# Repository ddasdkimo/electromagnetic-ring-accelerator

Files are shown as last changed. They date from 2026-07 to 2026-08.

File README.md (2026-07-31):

# 電磁環形加速器（Electromagnetic Ring Accelerator）

一個開源科學玩具：鋼球在 3D 列印的環形軌道上，經過線圈加速段被電磁脈衝吸力加速，繞一圈回到原點再次加速，循環往復直到飽和速度。原理是「磁阻式線圈砲（reluctance coilgun）」的環形循環版。

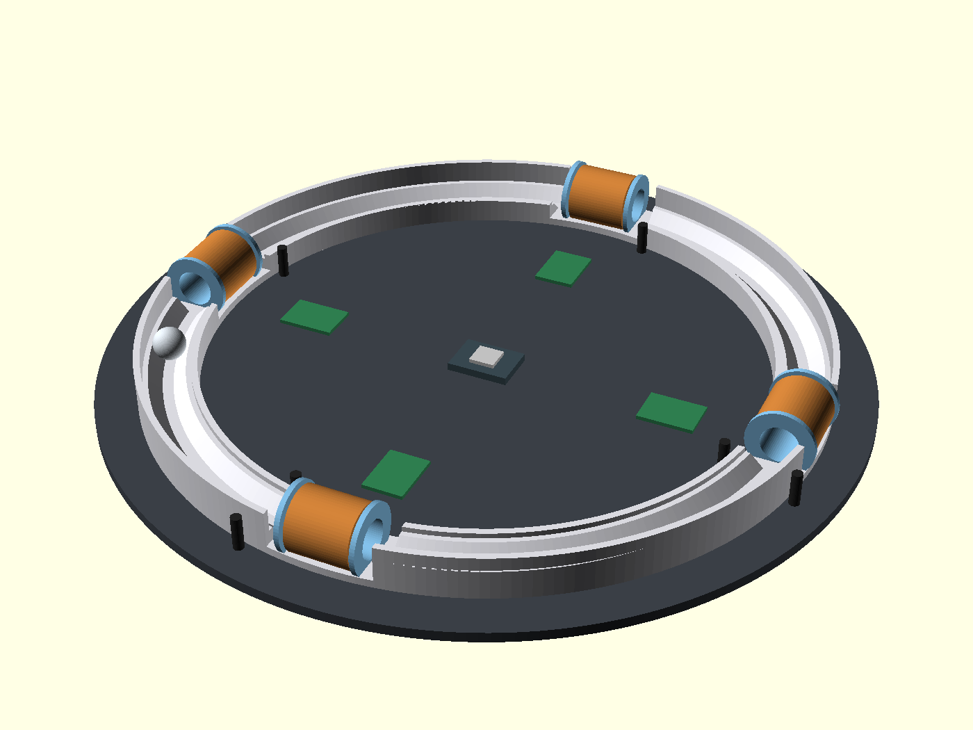
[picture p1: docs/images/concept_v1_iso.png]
概念示意圖

*第一版 3D 概念示意：Ø240 環軌、4 組線圈隧道（銅色）、IR 對射柱（黑）、每級驅動板（綠）與中央 ESP32-S3。模型：[hardware/concept/era_concept_v1.scad](hardware/concept/era_concept_v1.scad)*

> 🚧 專案狀態：**Phase 1 可行性驗證中**——單級直線原型（試配塊已出圖、電路已定稿、韌體已就緒，等待列印與零件到貨實測）。

## 它怎麼運作

1. 線圈通電產生磁場，把鐵磁性鋼球吸向線圈中心，過程中加速。
2. 關鍵在時機：球一過線圈中心，同一個磁場就會反過來拉住它（suck-back）——必須在球到達中心前斷電。
3. 紅外線對射管偵測球接近，ESP32 控制 MOSFET 給線圈一個精準寬度的脈衝。
4. 4 組線圈均布在 Ø240mm 環形軌道上，球每繞一圈被加速 4 次。

有趣的工程發現：在 0.5–3 m/s 的全速域，線圈電流都處於飽和區（τ≈0.65ms 遠短於最短脈寬），所以每級力道都接近上限——調校的重點完全在「關斷時機」，不在電流。

## 規格摘要

| 項目 | 規格 |
|---|---|
| 軌道 | Ø240mm 一體 3D 列印（PETG），45° 雙軌 U 槽 |
| 鋼球 | Ø12.7mm 軸承鋼球（鉻鋼） |
| 線圈 | 0.5mm 漆包線 × 290 匝（8 層），≈1.5Ω / ≈1mH |
| 驅動 | IRLB8721 低邊開關 + SS54 飛輪二極體，12V + 電容組 |
| 感測 | 940nm IR 對射 × 每級 2 道（觸發 + 測速） |
| 控制 | Seeed XIAO ESP32-S3，時序軟體可調 |

## 文件

- [RESEARCH.md](RESEARCH.md) — 原理研究與設計要點
- [PLAN.md](PLAN.md) — 定案方案與階段規劃
- [docs/design-v2-alt.md](docs/design-v2-alt.md) — 方案 B：獨立重新推導的替代設計（傾斜賽道、小球、直線段線圈）與 v1 對照
- [coil-and-driver-spec.md](coil-and-driver-spec.md) — 線圈估算與驅動電路規格（含電路圖）
- [firmware/p1_single_stage/](firmware/p1_single_stage/) — 單級驗證韌體（IR 觸發、脈寬調參、測速、安全保護）
- [docs/log/](docs/log/) — 開發日誌（build log）
- [hardware/preview/](hardware/preview/) — 方案 B 正式件預覽圖（四角件配色、分解圖、隧道剖切）

## 路線圖

- [x] 原理研究、方案定案
- [x] 試配塊 CAD/STL、電路規格、P1 韌體
- [ ] **Phase 1**：單級直線原型實測（驗證可行性）
- [ ] **Phase 2**：環形軌道 + 4 線圈整合
- [ ] **Phase 3**：測速顯示、玩具化收尾
- [ ] 製作影片與心得分享

## 授權

程式碼採 MIT，文件與硬體設計採 CC BY 4.0。歡迎自由複製改作，註明出處即可。

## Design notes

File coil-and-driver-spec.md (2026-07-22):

# 電磁環形加速器 — 單級線圈估算 + 驅動電路規格

> 由 my_car(XIAO ESP32-S3 專案工作區)協力估算。老闆已核可。
> 對應圖文頁:`~/code/2026/my_car/docs/emring-driver.html`(SVG 電路圖 + 表格)

## 前提假設
- 漆包線:0.5mm 裸銅徑(截面 A=π×0.25²=0.196 mm²,銅 ρ=1.72×10⁻⁸ Ω·m,≈0.088 Ω/m)
- 線圈:內徑 15.5mm(隧道外徑)、繞 8 層、約 280–300 匝(取 290 匝 ≈ 36 匝/層)、軸向長 ≈18mm
- 供電:12V;功率級 IRLB8721 + SS54;12V/5A + 5A 保險絲
- 下列為**空管(無鋼球)**估算;鋼球進入孔內時電感顯著上升(可 2–3 倍)

## 1. 線圈電氣參數

| 項目 | 估值 | 公式 / 說明 |
|---|---|---|
| 各層平均半徑 | 8.0 → 11.5 mm(均值 9.5mm) | 首層 15.5/2+0.25;每層 +0.5mm |
| 用線總長 | **≈ 17 m**(280–300 匝:16.7–17.9m) | Σ匝 × 2π·平均半徑 |
| 線圈直流電阻 | **≈ 1.5 Ω**(1.45–1.6) | R = ρL/A ≈ 0.088Ω/m × 17m |
| 迴路總電阻 | ≈ 1.55–1.65 Ω | +IRLB8721 Rds(on)(3.3V 閘極 ~0.016–0.025Ω)+佈線 |
| 電感(空管) | **≈ 0.9–1.1 mH** | Wheeler 多層式 ≈0.92mH;鋼球置中升 2–3× |
| **L/R 時間常數 τ** | **≈ 0.65 ms** | τ = L/R(空管) |
| 穩態電流(理論) | ≈ 7.7 A | 12V / 1.55Ω(需持續導通才達到) |
| **實際脈衝峰值** | **≈ 6–7 A** | 脈寬 1–1.5ms:I=I_max(1−e^(−t/τ)),1ms→6.1A、1.5ms→6.9A |
| 每脈衝磁能 | ½LI² ≈ 0.02 J | — |
| 每脈衝電阻熱 | I²R·t,隨脈寬(低速可達 1–2J) | 低工作週期整體散熱無虞 |

### ⚠️ 關鍵發現:12V/5A 供電偏緊
脈衝峰值 6–7A 超過 5A 額定 → 供電下垂、加速力道打折。
**對策:12V 端並電容組 2200–4700µF(低 ESR),放線圈附近**,由電容供給脈衝峰值、PSU 只補平均值(標準 coilgun 做法)。

### ✅ 元件裕度
- IRLB8721:連續 62A;Vgs(th) 1.35–2.35V,**3.3V 閘極可直驅**(比 IRLZ44N 適合 logic-level,不選 IRLZ44N 正確)。
- SS54(40V/5A 蕭特基):續流 6–7A 短脈衝,平均 5A、突波上百 A,綽綽有餘。

## 2. 建議單級脈衝寬度 vs 球速(0.5–3 m/s)

幾何近似 **w ≈ d_eff / v**,取有效加速段 d_eff ≈ 10mm(進入強力區到線圈中心)。
實務**提早 ~1–1.5ms(≈2τ)關斷**,讓電流尾流在球到中心前衰減、避免 suck-back。

| 球速 v (m/s) | 幾何脈寬 w=d_eff/v | 建議設定(扣 ~1ms 尾流) | 電流狀態 |
|---|---|---|---|
| 0.5 | ≈ 20 ms | ~19 ms | 飽和(~7.7A,注意單發熱) |
| 1.0 | ≈ 10 ms | ~9 ms | 飽和 |
| 1.5 | ≈ 6.7 ms | ~5.7 ms | 飽和 |
| 2.0 | ≈ 5.0 ms | ~4.0 ms | 飽和 |
| 2.5 | ≈ 4.0 ms | ~3.0 ms | 接近飽和 |
| 3.0 | ≈ 3.3 ms | ~2.3 ms | 接近飽和(仍 >電流建立所需) |

**重點結論:** 0.5–3 m/s 全落在「電流飽和區」(τ≈0.65ms,~3ms 就到穩態,而最短脈寬 3.3ms 仍大於電流建立時間)→ 每級電流都能充分建立、力道接近上限;**限制因素是幾何與時序,而非電流上升**。這對 suck-back 調校是好消息:專心調關斷時機即可。

## 3. 單級驅動電路(文字描述)

940nm IR 對射(光電晶體)→ XIAO ESP32-S3 GPIO → IRLB8721(100Ω 串聯 + 10k 下拉)→ 線圈 + SS54 飛輪 → 12V/5A + 5A 保險絲

```
        +12V ────┬──────────────┬───────────── (T5A 慢熔保險絲在此上游)
                 │              │
            [電容組]        線圈上端
          2200–4700µF          │
             (低ESR)         ▓▓▓▓▓  加速線圈 L≈1mH / R≈1.5Ω
                 │           線圈下端 = 節點 D
                 │              ├──────┐
                 │            [SS54]   │        SS54:陰極(帶環端)朝 +12V
                 │          陰極↑陽極↓  │              陽極朝 D。方向接反會短路燒毀。
                 │              │      │
                 │              D──────┘
                 │              │
                 │          [IRLB8721]  低邊開關
                 │           G   D   S
                 │           │       │
   ESP32 GPIO_OUT│──[100Ω]───┤       │
                 │           │       │
                 │         [10k]      │   閘極對地 10k 下拉
                 │           │        │
        GND ─────┴───────────┴────────┴─────────

   IR 發射: 3V3 ─[150–220Ω]─▷│(940nm LED)─ GND      (~15–20mA)
   IR 接收: 940nm 光電晶體, 集極→3V3, 射極→節點→[10k 下拉]→GND, 節點→ESP32 GPIO_IN
            ★ 接收輸出務必落在 0–3.3V,絕不可拉到 12V(會燒 ESP32)
```

### 接法重點
1. **低邊開關**:線圈上端固定 +12V,下端接汲極 D,源極 S 接 GND。
2. **SS54 飛輪**跨接線圈:陰極朝 +12V、陽極朝 D。關斷瞬間吸收線圈反電動勢。**接反=短路燒毀**。
3. **閘極**:GPIO_OUT → 100Ω 串聯 → IRLB8721 閘極;閘極對 GND 加 10k 下拉(開機/浮接確保關斷)。100Ω 開關較慢但振鈴/EMI 小,對單發脈衝夠用。
4. **IR 對射(940nm)**:發射端限流 150–220Ω;接收端輸出加 10k 拉,訊號 0–3.3V,**勿拉 12V**。
5. **保險絲**:12V 端串 **5A 慢熔(T5A)**,**電容組放保險絲之後、線圈之前** → 保險絲只看平均電流(遠小於 5A),脈衝峰值由電容供給,不會誤跳。**用快熔會被 6–7A 脈衝跳掉。**
6. **供電/接地**:ESP32 用自己的 USB 供電,**不要**用 12V 直供;但兩者**必須共地**。12V 大脈衝走粗線、星狀接地,ESP32 訊號地獨立回線,避免地彈跳誤觸發 IR。

## 4. Suck-back 時機 + 測速(ESP32 軟體)
- **Suck-back(吸回)**:鋼球過線圈中心後若還通電,磁力會把球往回拉減速。線圈必須在球**到中心之前**關斷;關斷後電流靠 τ(≈0.65ms)衰減,殘流也會吸,故要**提早關**。
- **時序**:IR 偵測球進入 → 延遲 d → 開 MOSFET 脈寬 w → 關。d、w 依球速逐級微調(這正是用 MCU 的價值)。
- **測速**:同一級用**兩道 940nm IR 對射(已知間距 s)**,量遮斷時間差 Δt → v = s/Δt。ESP32 即時算 v、預測到達中心時間、動態設定下一級 d/w,並記錄各級末速做效率評估。

## 5. 4 級系統延伸(對應你定案:4 路 IR 輸入 + 4 路 MOSFET 輸出)
- 每級一組上述電路;4 顆 MOSFET 閘極接 4 支獨立 GPIO。
- 4 路 IR 輸入建議用**帶硬體比較器/施密特**的模組(或軟體去彈),避免遮斷邊緣抖動誤觸。
- 共用 12V + 電容組;每級 MOSFET 汲極各自的 SS54。
- 一顆球通過:IR1 觸發→算速→開線圈1→...→IR4;逐級末速遞增即驗證加速有效。
```

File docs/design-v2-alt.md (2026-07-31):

# 方案 B：Banked-Square 4（v2 獨立重新設計）

> 這份是**不參考 v1 結論、從物理重新推導**的第二套設計，目的是與 [PLAN.md](../PLAN.md) 的 v1 方案對照。
> 推導過程中發現五個 v1 未涵蓋的量化問題，列在最前面。結尾有「v1 判斷正確、v2 沿用」的誠實清單。

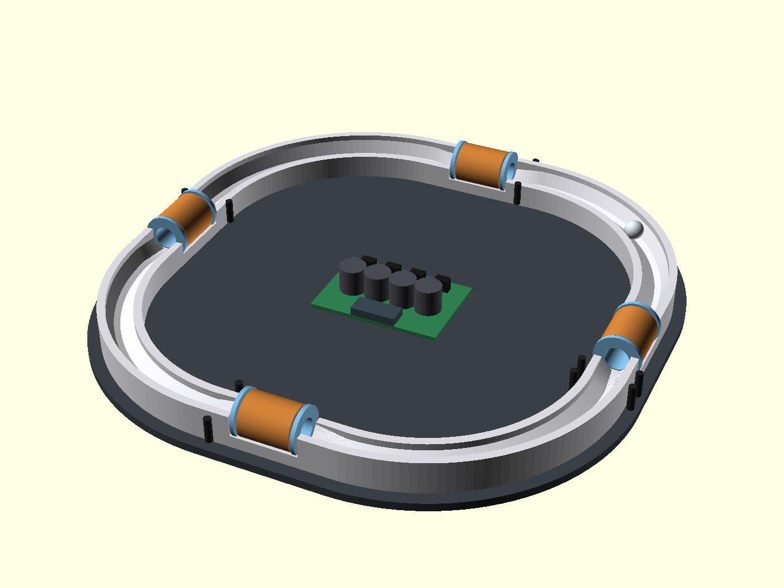
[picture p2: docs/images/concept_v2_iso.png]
v2 概念示意

*方案 B 概念示意：圓角方形軌道（4 直線段 + 4 傾斜彎道）、線圈全在直線段、中央集中驅動板。
模型：[hardware/concept/era_concept_v2.scad](../hardware/concept/era_concept_v2.scad)　俯視圖：[concept_v2_top.png](images/concept_v2_top.png)*

---

## 一、重新推導時發現的三件事

### 發現 1：閉合軌道的側向摩擦損失與軌道形狀完全無關

球轉彎時被外側軌道壁推著轉，側向正壓力 `N = m·v²/r`，沿弧長 `s = r·θ` 積分：

```
W_side = μ·N·s = μ·m·(v²/r)·(r·θ) = μ·m·v²·θ
```

`r` 消掉了。任何閉合迴路 `Σθ = 2π`，所以：

```
W_side = 2π·μ·m·v²   ← 只跟「球重、速度平方、接觸摩擦係數」有關
```

**推論：把軌道做大、做成跑道形、做成圓角方形，一圈的側向摩擦損失一模一樣。**
唯一能真正降低它的手段只有三個：減輕球、降速、**降低 μ**——而降 μ 的正解是**傾斜賽道（banking）**，讓側向力由「滾動的斜面支撐」承擔，而不是「滑動的側牆」。

### 發現 2：v1 的 45° V 槽在 1.08 m/s 就會失效

球騎在 45° 雙斜面上時是滾動接觸（低 μ≈0.02）。但當側向加速度超過斜面能提供的水平分量，球會爬上外壁改成滑動接觸（μ≈0.15，7 倍損失，且噪音與磨耗大增）。

剖面對照

臨界條件：`a_lat = g·tan(θ_外側面)`，`v_max = √(g·tanθ·R)`

| 設計 | 外側支撐角 | 側向承載 | 彎道 R | **乾淨滾動上限速度** |
|---|---|---|---|---|
| v1 | 45° | 1.00 g | 120 mm | **1.08 m/s** |
| v2（banking 20°） | 65° | 2.14 g | 85 mm | **1.34 m/s** |
| v2 極限（banking 25°） | 70° | 2.75 g | 85 mm | 1.52 m/s |

v1 的脈寬對照表涵蓋 0.5–3 m/s，但**物理上球到 1.08 m/s 就會離開 V 槽開始磨外牆**，之後每加速一點都要付 7 倍摩擦。實務巡航速度會卡在 1.1–1.5 m/s 且伴隨明顯磨擦聲。

→ v2 的第一改動：**彎道傾斜賽道（banking）**，成本為零，只是改剖面多邊形的頂點座標。

#### banking 的正確做法：整個 V 槽「繞球心旋轉」

這一步很容易做錯，我第一次也推錯了。兩種做法差很多：

| 做法 | 槽夾角 | 球心高度 | 結果 |
|---|---|---|---|
| ❌ 單獨掰彎兩個面（外 65°／內 35°） | 90°→80° | 比直線段**高 3.34 mm** | 過渡段變成 22% 的陡坡，球會撞上去 |
| ✅ 整個槽繞球心旋轉 20°（外 65°／內 25°） | 維持 90° | **完全不變** | 球心軌跡是水平平面曲線，過渡零高差 |

正解是後者——這正是真實賽車場 banking 的物理意義：**球心的高度與半徑都不動，只有支撐面轉了角度**。
槽的半夾角維持 45°，所以球陷入的深度不變（球心到虛擬頂點恆為 `r√2`）；banking 角 φ 只是把外側面轉成 `45°+φ`、內側面轉成 `45°−φ`。

側向承載只由外側面角度決定，所以承載提升的好處完整保留，而過渡問題自動消失。
φ 上限約 40°（內側面接近水平會失去停放穩定性），實用取 20–25°。

#### 發現 2b：隧道孔心不等於球心（stl 於出圖時抓出，2026-07-28）

我第一版派工單把隧道孔心寫成「= 球心高 8.218」，這是錯的。球在 bobbin 內孔裡是**躺在孔底滾**，不是懸浮在孔軸上：

```
球心 = 孔心 − (孔徑 − 球徑)/2 = 孔心 − (11.2 − 9.5)/2 = 孔心 − 0.85
→ 要讓球心維持 8.218，孔心必須是 9.068
```

若照原派工做，球一進隧道就會**跌落 0.85mm**——正好發生在加速段，是最不該有擾動的地方。

諷刺的是 v1 早就處理對了：`BALL_Z=9.98`、`BORE_Z=10.88`，差 0.90 = (14.5−12.7)/2。
我在 v2 沿用這段幾何時把這個關係弄丟了，寫成了 `BORE_Z = BALL_Z`。**這是 v1 做對、v2 一度做錯的一項。**

連帶修正：法蘭 Ø22 的下緣落在 `9.068 − 11 = −1.93mm`，低於底板基準面，法蘭會穿出底板。

**stl 定案（2026-07-28）：全周底板 3 → 6mm**。

推理過程值得記下來，因為前兩個直覺解都不行：

| 做法 | 為什麼不行 |
|---|---|
| 側面加肉 | 法蘭要的是基準面**下方**的空間，側面加肉在同一 z 範圍，沒用 |
| 只加厚線圈區 | 底面不再是同一平面，253mm 一體大件貼床不均會翹 |
| **全周底板 3→6** ✅ | 底面維持同一平面、貼床面積不減，法蘭槽開在 6mm 厚度裡 |

幾何一律不動，只是底面從 z=0 整體下移到 z=−3。
代價約 +58g（774mm 路徑 × 20 寬 × 3 厚，實心估），換來整圈剛性提升與零翹曲風險。

#### 但加厚還是不夠——最後靠 D 形法蘭釜底抽薪

底板加到 6mm 之後我再算一次膜厚，還是不對：

```
法蘭下緣 −1.932，沉槽挖到 −2.23（含餘裕），底面 −3
→ 剩餘膜厚僅 0.77mm      ← 在磁隙最敏感處，不可接受
```

問題的根源是**法蘭半徑 11 大於孔心到基準面的距離 6.068**，所以圓法蘭必然伸進基準面以下 4.93mm，
底板加多厚都只是把這 4.93mm 往下推，膜厚不會變。

**最終解（stl 定案）：法蘭改 D 形**——下緣截平於基準面下 0.5（z=2.5），沉槽只需挖到基準面下 0.8 的淺槽：

```
截平線距圓心 = 9.068 − 2.5 = 6.568
弦半寬 = √(11² − 6.568²) = 8.82  →  法蘭外形 22 × 17.6
底膜 = 5.20mm（stl CAD 取樣柱量測）
```

從「加厚以容納法蘭」變成「削掉法蘭用不到的部分」，膜厚問題直接消失。
D 形對立印姿態沒有影響。

#### 繞線注意：這副法蘭本來就擋不住線，D 形只是讓它更明顯

D 形的有效擋線角度值得算清楚。線圈外徑 20.8（半徑 10.4），法蘭半徑 11：

```
法蘭邊緣要高過線圈外緣，需距圓心 ≥ 10.4
截平弦上距中點 s 的點，距圓心 = √(6.568² + s²)
  → 需 s ≥ √(10.4² − 6.568²) = 8.06，而弦半長只有 8.82
無擋線角度 = 2·asin(8.06/11) = 94.2°  →  有效擋線 265.8°
```

而且缺口最低點的法蘭半徑 6.568，只比 bobbin 筒身半徑 6.4 高出 **0.168mm**——那一段等於完全沒有側擋。

不過真正的重點是：**即使用完整圓法蘭，裕度也只有 (11 − 10.4) = 0.6mm**，對 0.5mm 漆包線
只夠擋一層多一點。這副 bobbin 從一開始就不是靠法蘭擋線的，是靠繞線張力；D 形只是把這件事挑明。

→ 繞線務必**全程保持張力**，繞完立刻用膠帶／熱縮套／少量瞬間膠固定端頭，不要指望法蘭。
→ 若實測發現線容易鬆脫，截平位置可下修：`z_cut` 越低法蘭越完整，代價是底膜變薄。

| z_cut | 底膜 | 無擋線角度 |
|---|---|---|
| 2.5（現行） | 5.20 mm | 94.2° |
| 1.5 | 4.2 mm | 80.8° |
| ≤ 0.12 | — | 弦半寬會小於筒身半徑，法蘭切進筒身，不可用 |

#### 通則：凡是「圓的東西躺在圓孔裡」，孔心都要抬半個間隙

孔心那個錯不是一次性的失誤——同一個關係在這個專案裡出現了**三次**，其中兩次是 bug：

```
孔心 = 物體軸心 + (孔徑 − 物體徑) / 2
```

| 應用 | 孔徑 / 物體 | 孔心 | 物體軸心 |
|---|---|---|---|
| bobbin 內孔 / 鋼球 | 11.2 / 9.5 | **12.068** | 11.218 |
| IR 夾座槽 / 對射管 | 3.2 / 3.0 | **11.100** | 11.000 |
| ❌ 光路孔誤當定位槽 | 3.5 / 3.0 | 11.000 | **10.750**（偏低 0.25） |

第三列是 stl 在做 IR 夾座時自己踩到並修掉的：光路孔 Ø3.5 一路打穿夾座立柱，
而它比定位槽 Ø3.2 大、孔底（9.25）比槽底（9.5）低，元件會滑進去落到孔底，光軸偏低 0.25mm。
修法是**讓光路孔止於軌道外緣 ±10.5、不進立柱**（實測 STL 頂點確認孔底只到 |x|=10.500 ✓）。

會重複踩到是因為這個關係違反直覺——直覺會說「讓孔心對準物體要走的高度」，
但物體是**躺在孔底**的，不是懸在孔心。定位面是孔的底部，不是孔的軸線。

> 檢查方法：問「這個東西靠什麼面定位？」如果答案是孔的底部，那孔心就不等於物體軸心。

#### 順帶：v1 概念圖的剖面與它自己的球心算式對不上

檢查 `hardware/concept/era_concept_v1.scad` 的 `track_profile()` 多邊形時發現：

```
外側斜面 [20.5,8] → [13.5,3]：Δx=7、Δz=5  →  35.5°   ← 不是 45°
內側斜面 [9.5,3]  → [4.5,8] ：Δx=5、Δz=5  →  45°
```

但同一份檔案的 `BALL_Z = 9.98` 是按**對稱 45°** 算出來的（`r√2 − 平底半寬 + 底板 = 6.35×1.4142 − 2 + 3 = 9.98`）。
兩者不一致，而且錯的方向最不利——**外側比內側還緩**，正好是離心力要壓過去的那一面。

**已向 stl 確認（2026-07-28）：正式件的出圖一直是對稱 45°（Δx=5/Δz=5，與球心 9.98 自洽），
35.5° 只存在於我們的 `era_concept_v1.scad` 示意檔中。**
根因是外側漏了斜面頂點 `[18.5,8]`，多邊形從 `[20.5,8]` 直接連到 `[13.5,3]`。已補上並重新渲染，
v1 的設計本身沒有問題。

### 發現 3：Ø240 圓環上放 30mm 直線圈，球一定會撞隧道壁

直 bobbin 的軸線是圓的**弦**，球從弧形軌道出來時速度沿**切線**，兩者夾角：

```
α = asin(L/2R) = asin(15/120) = 7.18°
30mm 行程的橫向漂移 = 30 × tan(7.18°) = 3.78 mm
隧道總間隙 = 14.5 − 12.7 = 1.8 mm      ← 漂移是間隙的 2.1 倍
```

球會斜著撞進隧道口、沿壁刮擦通過，動能損失與噪音都在最不該發生的地方（加速段）。縮短線圈到 12mm 才勉強達標，但那樣安匝與加速行程都不夠。

→ v2 的第二改動：**軌道改圓角方形，線圈全部放在直線段**，入口角歸零。
（備選：把 bobbin 做成弧形骨架沿 R=120 彎曲，也能解，但手繞弧形筒麻煩。）

---

## 二、第四個發現：恆壓驅動下「安匝與匝數無關」

磁阻力正比於安匝數平方 `(N·I)²`。恆壓驅動時 `I = V/R`，而 `R = ρ·N·l_turn/A`：

```
N·I = N · V·A/(ρ·N·l_turn) = V·A / (ρ·l_turn)
                              ↑ N 消掉了
```

**安匝只由「電壓、線徑截面、平均匝長」決定，繞幾匝完全不影響力道。**
匝數只決定電流大小與電感（響應速度），不決定推力。

這帶來 v2 最大的免費性能槓桿——**把球變小**：

| | v1（Ø12.7 球） | v2（Ø9.5 球） |
|---|---|---|
| 球質量 | 8.38 g | **3.52 g**（0.42×）|
| bobbin 內孔 | 14.5 mm | 11.2 mm |
| 線圈平均匝徑 | 20.0 mm | 15.6 mm |
| 平均匝長 | 62.8 mm | 49.0 mm |
| **安匝（12V、0.5mm 線）** | 2 180 At | **3 200 At**（1.47×）|
| 磁阻力 ∝ (NI)² | 1.00 | **2.15×** |
| **加速度 = 力/質量** | 1.00 | **5.1×** |

球小 → 線圈小 → 匝長短 → 同樣線徑同樣電壓下電阻低、電流大、安匝反而多；同時質量掉一半以上。**加速度提升 5 倍，而且鋼球更便宜、漆包線更省。**

代價：小球對軌道層紋與接縫更敏感（同樣 0.2mm 台階，對 9.5mm 球是相對 2.1% 的障礙，對 12.7mm 球是 1.6%），軌道表面品質要求提高。

---

## 三、第五個發現：v1 的電容組電荷帳沒算過

v1 寫「線圈旁並 2200–4700µF 供脈衝峰值」。實際算一次電荷：

```
單脈衝電荷 Q = I × w = 8A × 10ms = 80 mC
12V/5A 電源在脈衝期間只能供 5A × 10ms = 50 mC
電容必須補 30 mC
```

若只裝 2 顆 2200µF（4400µF），壓降 = 30mC / 4.4mF = **6.8V** → 電壓垮掉一半，力道剩 1/4。

正確做法是把電容組加大並**集中並聯**（4 級不會同時開，分散裝反而各自不夠）：

| 電容組 | v1 @8A/10ms 壓降 | v2 @11A/7ms 壓降 |
|---|---|---|
| 4 400 µF | 6.8 V ❌ | 9.5 V ❌ |
| 9 400 µF | 3.2 V ⚠️ | 4.5 V ⚠️ |
| **18 800 µF（4700×4 並聯）** | **1.6 V ✅** | **2.2 V ✅** |

充電恢復：每級每圈觸發一次（約 0.6s 一次），補 42mC 只需 8.4ms，5A 電源綽綽有餘。

→ v2 明確規定：**4700µF/25V 低 ESR × 4 全部並聯在集中驅動板上**，不分散。
（好消息：v1 採購清單第 5 項本來就寫「2–4 顆」，買到 4 顆就對了，這項不用改單。）

---

## 四、v2 規格表

| 項目 | 規格 | 理由 |
|---|---|---|
| **佈局** | 圓角方形：直線段 60mm ×4 + 彎道 R=85mm ×4（90°），彎心在 (±30, ±30) | 線圈全在直線段，入口角 0° |
| 外廓 / 周長 | 253 × 253 mm / 774 mm | 256 床單件一體印，仍無接縫 |
| **剖面（直線段）** | 對稱 45° V 槽，平底寬 3mm，球心高 5.218mm（相對槽底） | 停放穩定、進出線圈對中 |
| **剖面（彎道）** | 同一個槽繞球心旋轉 20°：外側面 65°、內側面 25°，**球心高度與半徑不變** | 側向承載 2.14g，過渡零高差 |
| **緩和段** | 直線段兩端各 15mm，僅 banking 角 0°→20° 線性漸變（線圈只用中間 30mm） | 球心軌跡全程是水平平面曲線 |
| 鋼球 | **Ø9.5mm（3/8")** 鉻鋼 GCr15，3.52g | 加速度 5.1×、摩擦損失 0.42× |
| bobbin | 內孔 11.2mm、壁 0.8mm、長 30mm、**D 形法蘭 22×17.6**（下緣截平於基準面下 0.5） | 磁隙 0.85mm/邊；截平換來 5.2mm 底膜 |
| **隧道孔心高** | **9.068mm**（= 球心 8.218 + 間隙/2 0.85） | 球躺孔底滾，不是懸在孔心 |
| 底板 | **全周 3 → 6mm**（幾何不動，底面整體下移至 z=−3） | 法蘭需要基準面下方空間；只加厚線圈區會讓底面不平 |
| 線圈 | 0.5mm 漆包線 × 290 匝（8 層），≈1.09Ω / ≈0.6mH，τ≈0.55ms | 安匝 3200 At、峰值 ~10–11A |
| 續流二極體 | **MBR1045 / SB1045（10A/45V）**，或 SS54 ×2 並聯 | 11A 超過 SS54 的 5A 連續額定 |
| 電容組 | 4700µF/25V 低 ESR **×4 並聯，集中** | 見發現 5 |
| 電源 | 12V / 5A（沿用） | 平均功耗僅 ~0.13A，只有瞬時問題，已由電容解決 |
| MOSFET | IRLB8721 ×4（沿用），免散熱片 | 11A×12mΩ×1.2% duty = 0.02W 平均 |
| **感測** | 每級 1 道 IR 觸發（4 對）+ 基準級加 1 道測速（共 **5 對**） | 見下 |
| 控制 | XIAO ESP32-S3（沿用），**非阻塞 esp_timer 時序** | 4 級並行不能用 busy-wait |
| 脈寬起手 | d_eff≈8mm → w ≈ 8/v ms（1.0m/s→8ms、1.34→6ms、0.5→16ms） | |

### 感測方案簡化

v1 每級 2 道 IR = 8 對、16 個對穿孔。v2 改成：

- **每級 1 道觸發 IR**（球到 → 延遲 d → 脈寬 w）
- **速度由級間飛行時間反推**：級距固定 193.5mm，第 N 級與第 N−1 級觸發時戳相減即得平均速度
- **保留 1 級雙 IR** 作為速度標定基準（校正級間法的系統偏差）

省一半接線與孔位，且環形本來就在循環，速度資訊天然存在。
代價：級間法測的是「上一段平均速度」，加速期會略低估 → 脈寬偏長 → 有 suck-back 風險，所以保留基準級做校正。

### 必須新增：軟體限速（巡航控制）

v2 加速度是 v1 的 5 倍，球會一路加速直到撞上 banking 上限 1.34 m/s 然後開始磨外牆。
因此韌體必須做：**測得速度 ≥ 目標速度時跳過該級脈衝**。

這反而是玩具的賣點——可以做「設定巡航速度」、OLED 顯示即時速度、加減速展示。v1 因為推力小可能自然平衡，v2 是主動控制。

---

## 四之二、分件架構選項：「縫藏隧道」

一體印和分件卡榫本來是矛盾的——v2 從一開始就主張一體無縫（鋼球對 0.1mm 台階敏感）。
但 David 提出正式件分件的需求後，stl 找到了調和方案：

**把接縫藏在球摸不到的地方。**

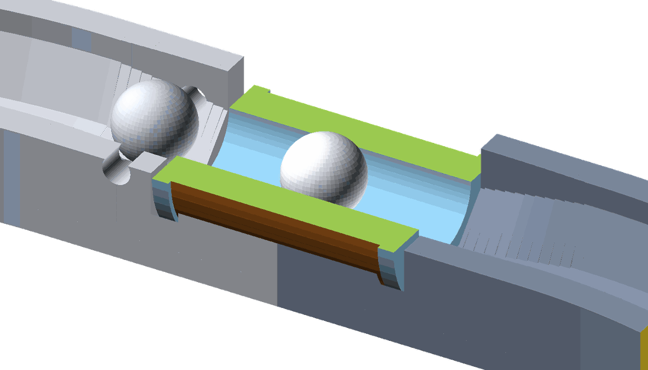
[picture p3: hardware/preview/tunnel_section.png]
隧道剖切

*綠色是 bobbin、藍色是內孔。軌道在線圈段正中斷開，球在隧道內全程騎 bobbin 內孔，摸不到接縫。*

軌道在**線圈段正中**斷開。球通過該處時正在 bobbin 內孔裡（bobbin 長 30，接縫在正中，
球半徑 4.75，兩端各有 15mm 餘裕），接觸的是 bobbin 內孔面而不是軌道——**接縫對球不存在**。

| | 一體印（combo 路線） | 四角件（joint 路線） |
|---|---|---|
| 尺寸 | 253×253 一件 | 4 件各約 145×145 |
| 印壞成本 | 整件報廢 | 重印一角 |
| 翹曲風險 | 大件風險高 | 小件風險低 |
| 接縫 | 無 | 4 個，都藏在隧道內 |
| 對位 | 不需要 | 底部燕尾舌（0.4 間隙）+ bobbin 兼對位銷 |
| 額外需求 | 無 | 需底座提供剛性基準 |

分件版的接合設計（實測 `test_v2_joint_a/b`）：接縫面在 y=30，燕尾搭接 9mm。
**燕尾正上方就是線圈坑**，所以舌中央只有 1.25mm 厚、倒鉤區 2.5–3.0mm，鎖定作用在倒鉤區。
→ stl 建議正式件配底座螺絲，不讓燕尾吃結構力。這個定位是對的：
**燕尾負責對位、螺絲負責承力**，加上 bobbin 本身跨縫兼對位銷，等於三重定位。

### 這裡有一個幾何必然，改不掉

線圈區的底膜只有 **1.268mm**（實測），因為線圈 Ø20.8 的最低點在 z=1.668，
比法蘭 D 面（z=5.5）還低 3.83mm——法蘭區能靠 D 形截平把底膜救回 5.35，
**線圈區沒有這個餘地**。該區剛性要算兩側側牆，不能算底膜。

而分件版的 4 個接縫，正好都落在這個最薄的位置上。這是分件方案要用實測回答的問題。

### 建議的決策方式

不必現在二選一——兩版共用同一個參數化模型，切不切只是一個開關。
合理的做法是 **迭代期用分件**（印壞重印一角，改設計成本低），
**確認幾何全對之後，展示件用一體印**（無縫、最可靠）。
David 的 Bambu H2D（300×320×320）床夠大，一體印始終是可行選項。

## 五、v1 vs v2 對照

| | v1（Ring-4） | v2（Banked-Square 4） | 差異來源 |
|---|---|---|---|
| 軌道形狀 | Ø240 正圓環 | 253mm 圓角方形（直線+彎道） | 發現 3 |
| 線圈入口角 | 7.18°（漂移 3.78mm > 間隙 1.8mm）❌ | 0° ✅ | 發現 3 |
| 剖面 | 全程對稱 45° | 直線 45°／彎道 banking 20°（65°+25°） | 發現 1、2 |
| 乾淨滾動上限 | 1.08 m/s | 1.34 m/s | 發現 2 |
| 鋼球 | Ø12.7 / 8.38g | Ø9.5 / 3.52g | 發現 4 |
| 安匝 | 2 180 At | 3 200 At | 發現 4 |
| 加速度 | 1× | **5.1×** | 發現 4 |
| 每圈摩擦損失 @1.0m/s | ≈2.0 mJ | ≈0.9 mJ | 發現 1、4 |
| IR 對數 | 8 | 5 | 級間測速 |
| 驅動板 | 4 片分散 + 星狀接地 | 1 片集中，單點接地 | 除錯與接地品質 |
| 電容 | 2–4 顆分散 | 4 顆集中並聯（18800µF） | 發現 5 |
| 續流二極體 | SS54（5A） | MBR1045（10A）或 SS54×2 | 峰值 11A |
| 韌體時序 | 阻塞式 busy-wait | 非阻塞 esp_timer × 4 級 | Phase 2 必要 |
| 速度控制 | 無（自然平衡） | 主動限速巡航 | 推力過剩 |
| 周長 | 754 mm | 774 mm | — |

## 六、v1 判斷正確、v2 原封沿用

不為了不同而不同。以下 v1 的決策我重新算過，結論是它對：

- **磁阻式 + IR 觸發 + MOSFET 低邊開關**——這個架構本身沒有更好的替代
- **12V 而非高壓電容放電**——科學玩具的安全性遠比極致速度重要，且循環補能不需要大能量
- **IRLB8721**（3.3V 真 logic-level，TO-220 好焊）
- **一體列印無接縫**（鋼球對 0.1mm 台階極敏感，這個判斷完全正確）
- **PETG 而非 PLA**（線圈發熱，PLA 55°C 會軟）
- **IR 光電晶體集極輸出 + 內部上拉，遮光/斷線皆 HIGH**——fail-safe 極性選得漂亮，這是全案最好的一個決策
- **T5A 慢熔保險絲、電容組接在保險絲之後**
- **12V/5A 電源**（重算平均功耗僅 0.13A，v1 選型沒問題，問題只在電容量）
- **0.5mm 漆包線 8 層**（線徑是安匝的主要槓桿，0.5 是繞線手感與安匝的甜蜜點）

---

## 七、對已完成工作與採購的影響

| 項目 | 影響 | 說明 |
|---|---|---|
| 漆包線 0.5mm ×2 捲 | ✅ 不變 | v2 線更省（匝長短 22%）|
| IRLB8721 ×6 | ✅ 不變 | |
| IR 對射管 ×8 對 | ✅ 不變 | v2 只用 5 對，更寬裕 |
| 電容 2200–4700µF | ⚠️ **改買 4700µF ×4** | 原「2–4 顆」→ 明確 4 顆 4700 |
| 12V/5A 電源、T5A 保險絲 | ✅ 不變 | |
| **鋼球 12.7mm** | ❌ **改 9.5mm（3/8"）** | 尚未下單，現在改零成本 |
| **SS54 ×6** | ⚠️ **加購 MBR1045 ×6** 或 SS54 買 12 顆並聯 | 峰值 11A |
| 電阻包 | ✅ 不變 | 100Ω / 10kΩ 需求相同 |
| 洞洞板 | ⚠️ 改買 1 片大板（7×9cm）取代 4 小片 | 集中驅動板 |
| **試配塊 STL** | ❌ **需重出**：bobbin 內孔 11.2、軌道改 banked 剖面 | 若尚未列印，等新檔 |
| P1 韌體 | ⚠️ 參數改（d_eff 8mm、脈寬表重算），架構不變 | 單級驗證邏輯完全可沿用 |
| coil-and-driver-spec.md | ⚠️ 線圈參數需重算（1.09Ω / 0.6mH / 11A） | |

## 八、v2 未驗證的風險（誠實列出）

1. **9.5mm 小球對列印表面品質更敏感**——若試印後滾動不順，回退 12.7mm 只需放大 bobbin 內孔與槽寬，banking 設計不受影響。
2. **65° 外側面的實際 μ**——理論上仍是滾動接觸，但接觸點靠近球赤道時差速滑移增加，實測可能比 0.02 高。
3. **緩和段仍有「扭轉」**——球心高度不變了，但槽面在 15mm 內轉 20°，球與槽的接觸點會沿球面移動，可能有輕微的滾動軸擾動。做長到 20–25mm 更保險。
4. **圓角方形 + banking 的 SCAD 建模比 rotate_extrude 複雜**——需要直段 linear_extrude + 彎道 rotate_extrude + 漸變段分段內插拼接（概念圖用 15 片近似），正式件應改用連續掃掠，出圖工時較高。
5. **11A 峰值下的線圈溫升**——132W 瞬時、1.2% duty → 平均 1.6W，估計溫升 20–30°C，PETG 安全，但連續高速運轉需實測。
6. **級間飛行時間測速在加速期會低估**——已用基準級校正，但第一圈仍需保守長脈寬冷啟動。

---

*本文件為 v2 獨立設計提案，與 v1 並存供比較，未取代 [PLAN.md](../PLAN.md)。*

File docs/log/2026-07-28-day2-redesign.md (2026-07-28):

# 開發日誌 Day 2（2026-07-28）：重新設計一次，然後在四個來回裡被抓出三個錯

> 部落格素材原稿。這篇的主角不是設計本身，是**兩個 AI 互相審查、一路收斂**的過程。

## 起點：「我換了新模型，重新設計一套讓我比較差異」

Day 1 的方案（v1）已經 ready-to-build，試配塊出圖、電路定稿、韌體就緒。
這時 David 換了模型，要求**不參考 v1 結論、從物理重新推一套**來對照。

這種要求很有意思：如果只是把 v1 微調一下改個名字，那是自欺欺人；
但如果真的從頭推，就必須承擔「推出來的東西可能跟 v1 一樣」的風險——那反而是好消息，代表 v1 是對的。

結果是五個 v1 沒算到的量化結果，其中兩個直接推翻了 v1 的可行速度範圍。

## 重推得到的五件事

### 1. 閉合軌道的側向摩擦與形狀無關

球轉彎被外壁推著走，摩擦功 `W = μ·(mv²/r)·(rθ)` —— **半徑消掉了**。
一圈 `Σθ = 2π`，所以任何閉合迴路都是 `W = 2π·μ·m·v²`。

把軌道做大、做成跑道形、做成圓角方形，一圈的側向摩擦**完全一樣**。
能改的只有 μ 和 m。這一條直接砍掉了「把環做大來減少損失」這個直覺選項。

### 2. v1 的 45° V 槽在 1.08 m/s 就失效

球一旦爬上外側壁，接觸從滾動（μ≈0.02）變成滑動（μ≈0.15），損失跳 7 倍。
臨界條件 `a_lat = g·tan(θ外)`，v1 的 45° 只給 1.0g，`v_max = √(1×9.8×0.12) = 1.08 m/s`。

而 v1 的脈寬對照表涵蓋 0.5–3 m/s——**上面三分之二的速度範圍在物理上是磨著牆跑的**。

解法是傾斜賽道：彎道 banking 20°（外側面 65°），上限拉到 1.34 m/s，**改動成本是零**，
只是移動剖面多邊形的頂點。

### 3. 圓環上放直線圈，球一定刮壁

直 bobbin 的軸線是圓的弦，球出彎時速度沿切線。Ø240 環上 30mm 的線圈：

```
入口角 = asin(15/120) = 7.18°
橫向漂移 = 30 × tan(7.18°) = 3.78mm     隧道間隙只有 1.8mm
```

漂移是間隙的 2.1 倍，球會斜著撞進隧道口刮著過去——而且是在加速段。
解法：軌道改圓角方形，線圈全放直線段，入口角歸零。

### 4. 恆壓驅動下，安匝與匝數無關

這條最反直覺。磁阻力 ∝ `(N·I)²`，而恆壓時 `I = V/R`、`R = ρ·N·l/A`：

```
N·I = N · V·A/(ρ·N·l) = V·A/(ρ·l)      ← N 消掉了
```

**繞幾匝完全不影響力道**，只由電壓、線徑截面、平均匝長決定。
於是「把球變小」成了免費的大槓桿：球小 → 線圈小 → 匝長短 → 安匝反而增加。

Ø12.7 換成 Ø9.5：安匝 +47%、質量降到 0.42×、**加速度 5.1 倍**。

### 5. 電容組的電荷帳從來沒算過

v1 寫「線圈旁並 2200–4700µF 供脈衝峰值」。實際算：

```
單脈衝需要 8A × 10ms = 80mC
12V/5A 電源在脈衝期間只給得起 50mC
→ 電容要補 30mC，4400µF 會垮 6.8V，力道剩 1/4
```

要 4700µF×4 集中並聯（18800µF）壓降才回到 1.6V。
好消息是採購清單本來就寫「2–4 顆」，買滿就對了。

## 然後把它派給 CAD，被打回來

方案寫完、概念圖渲染完、派工單送給負責 CAD 的 `stl` session。
出圖回來附了一句「請核定兩項規格修正」——第一項就打中要害：

### 錯誤 1（我的）：隧道孔心不等於球心

我在派工單寫「隧道孔心 = 球心高 8.218」。錯了。
**球在 bobbin 內孔是躺在孔底滾的，不是懸浮在孔軸上：**

```
球心 = 孔心 − (11.2 − 9.5)/2 = 孔心 − 0.85
→ 孔心必須是 9.068，球心才會維持 8.218
```

照我的派工做，球一進隧道就跌 0.85mm——正好跌在最不該有擾動的加速段。

最諷刺的是 **v1 早就處理對了**（`BALL_Z=9.98`、`BORE_Z=10.88`，差 0.90 = (14.5−12.7)/2）。
我在 v2 沿用這段幾何時，把這個關係寫成了 `BORE_Z = BALL_Z`，把它弄丟了。

> 教訓：重新設計時，最危險的不是你重新推導的部分，是你「照抄」的部分。
> 重推過的地方都被檢查過，抄過來的地方沒有。

### 錯誤 2（我的）：法蘭會穿出底板

連帶問題：法蘭 Ø22 的下緣落在 `9.068 − 11 = −1.93mm`，低於底板基準面。

這裡的來回很有意思，因為**前兩個直覺解都不行**：

| 做法 | 為什麼不行 |
|---|---|
| 側面加肉 | 法蘭要的是基準面**下方**的空間，側面加肉在同一 z 範圍 |
| 只加厚線圈區 | 底面不再同一平面，253mm 一體件貼床不均會翹 |
| 全周底板 3→6 | 底面平了，但膜厚還是只有 0.77mm |

第三個是 stl 提的、我核定的，結果**我們兩個都算錯了膜厚**（它心算成 3.5，我算 0.77）。
它承認算錯之後，順著問題本質找到真正的解：

**根源是法蘭半徑 11 > 孔心到基準面的距離 6.068**，所以圓法蘭必然伸進基準面下 4.93mm，
底板加多厚都只是把這 4.93mm 往下推，膜厚永遠不會變。

**解法：法蘭改 D 形**，下緣截平於基準面下 0.5：

```
截平距圓心 = 9.068 − 2.5 = 6.568
弦半寬 = √(11² − 6.568²) = 8.82   →  外形 22 × 17.6
底膜 = 5.20mm
```

從「加厚以容納法蘭」翻成「削掉法蘭用不到的部分」，膜厚問題直接消失。

### 錯誤 3（它的）：D 形的擋線角度

stl 說「D 形對繞線無影響，法蘭仍有 300°+ 擋線」。這個我算不出來：

```
法蘭邊緣要高過線圈外緣（半徑 10.4），需距圓心 ≥ 10.4
截平弦上距中點 s 的點距圓心 = √(6.568² + s²)
→ 需 s ≥ 8.06，而弦半長只有 8.82
無擋線角 = 2·asin(8.06/11) = 94.2°   →   有效擋線 265.8°
```

而且缺口最低點的法蘭半徑 6.568，只比 bobbin 筒身半徑 6.4 高出 **0.168mm**——那一段等於完全沒側擋。

但追下去發現真正的重點不是 D 形造成的：**即使用完整圓法蘭，裕度也只有 (11−10.4) = 0.6mm**，
對 0.5mm 漆包線只夠擋一層多一點。這副 bobbin 從一開始就不是靠法蘭擋線的，是靠繞線張力。

**D 形沒有製造這個問題，它只是把一個一直存在的問題挑明。**

所以結論是不改設計，改寫文件：繞線全程保持張力、繞完立刻固定端頭。
並把截平高度參數化，留一個備案：`Z_CUT` 從 2.5 下修到 1.5，無擋線角降到 80.8°，底膜 5.2→4.2 仍充裕。

## 另外還翻出一個 v1 的舊帳

重推時順手檢查 v1 的概念圖，發現 `track_profile()` 的外側斜面實際只有 **35.5°**，
但同一份檔案的 `BALL_Z = 9.98` 是按對稱 45° 算的。而且錯的方向最不利——外側比內側還緩，
**正好是離心力要壓過去的那一面**。

問了 stl，答案是：它的正式件出圖一直是對稱 45°，35.5° 只存在於我們的示意檔裡。
追根因是多邊形漏了一個頂點 `[18.5,8]`，從 `[20.5,8]` 直接連到了 `[13.5,3]`。

v1 的設計沒問題，錯的是那張給人看的圖。

## 四個來回之後

| 誰抓到誰 | 內容 |
|---|---|
| stl → 我 | 隧道孔心 8.218 → 9.068（球躺孔底滾） |
| stl → 我 | 法蘭穿出底板，且側面加肉解不了 |
| 我 → stl | 膜厚 3.5 算錯了，實際 0.77（它收回並找到 D 形解） |
| 我 → stl | 擋線 300°+ 算錯了，實際 265.8° |
| 我 → v1 | 概念圖漏頂點導致 35.5°（設計無誤，圖有誤） |

## 三個關於「怎麼做設計」的心得

**1. 獨立重推的價值不在於推出不同答案，在於推出「同樣答案的不同理由」。**
v2 有一長串「v1 判斷正確、原封沿用」的清單——磁阻式架構、12V 而非高壓、一體無接縫、PETG、
IR 集極輸出的 fail-safe 極性。這些在重推後依然成立，反而讓人更敢往下做。

**2. 最危險的不是你算錯的地方，是你沒算的地方。**
隧道孔心那個錯，是因為我「沿用 v1 幾何」而沒重算。重推過的每一處都經得起檢查，
抄過來的那一處出了事。

**3. 「錯的方向」比「錯的數值」更值得注意。**
v1 概念圖的 35.5°、v2 的孔心 −0.85mm，兩個錯都不大，但方向都是**最不利的那一邊**：
一個讓離心力去壓最緩的面，一個讓球在加速段往下跌。數值錯了會被實測抓到，
方向錯了會讓實測結果變得難以解讀。

## 目前狀態

v2 完整設計 + 三件試配塊（含 D 形法蘭新版）已就緒並公開在 repo。
所有幾何經 CAD 驗證：球心 8.218 於直線段／漸變段中點／彎道 22.5° 三處恰相切，干涉 0.000。

接下來卡在實體動作：印試配塊、下單零件。
實測要看四項——滾動順暢度、**banking 過渡有沒有頓一下**（這是 v2 全案的核心假設）、
0.8mm 壁品質、IR 對光。

過了就出正式件。

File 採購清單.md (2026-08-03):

# 採購清單（已核可 2026-07-22，David 執行下單）

依 my_car 單級估算修訂：線圈 ≈1.5Ω/≈1mH、脈衝峰值 6–7A、每脈衝熱 0.08J。
⚠️ 重要新增：**12V 端須並低 ESR 電解電容 2200–4700µF** 放線圈旁供脈衝峰值（12V/5A 電源只補平均，否則峰值時電壓下垂力道打折）。

## 必買（✅ = 2026-08-03 已下單，⬜ = 尚未購）

| # | 狀態 | 品項 | 規格 | 數量 | 建議來源 / 關鍵字 |
|---|---|---|---|---|---|
| 1 | ✅ | 漆包線 | 0.5mm（#25）100g | 2 捲 | ⭐**蝦皮實查**：[漆包線 SWG #14~#47 100g](https://shopee.tw/product/71613488/27211691243) 選 **#25 / 0.5mm**，$165（9折券後約$149），8/5–8/6 到。備選 [今華電子](https://jin-hua.com.tw/webc/html/product/show.aspx?num=533)、[禾樺電子](https://www.ho-hua.com.tw/h/ProductDetail?key=hmqg3&productId=422585)。**注意按長度賣的（如環島科技 0.5mm 只有 10 米）不夠用，單線圈就要 15.3 米** |
| 2 | ⬜ | N-ch MOSFET | **IRLZ44N**（TO-220，55V/47A，**Vgs(th) max 2.0V**，3.3V 可直驅）。原訂 IRLB8721PBF 亦合格，見下方調查節 | 6 | ⭐**蝦皮實查**：[傑森創工](https://shopee.tw/product/20917936/23024196080) $25/顆，9 年店／4.2 萬評價、本品已售 1000+，8/5–8/7 到。<br>⚠️⚠️ **下單前逐字核對料號：勿買 IRFZ44N**（只差一個字母 L）——IRFZ44N 的 Vgs(th) 為 2–4V，**非 logic level，3.3V 驅動會半導通燒毀**。搜尋結果兩者大量混雜。 |
| 3 | ✅ | IR 對射管 | 3mm 940nm IR LED + 光電晶體（成對，單顆裝） | 8 對 | ⭐**蝦皮實查**：[祥昌電子（單顆 $3）](https://shopee.tw/product/27742636/29053212103) 選「**3mm發射器 940nm(透明)**」與「**3mm接收器(黑色)**」各 N 顆，5.0 分/已售 4000+，8/5–8/7 到。⚠️ 收到要確認接收端是**光電晶體**而非 38kHz 解調接收頭——解調型只對調變光反應，連續光遮斷會失效 |
| 4 | ✅ | 蕭特基二極體 | ~~SS54（5A/40V）~~ → **MBRF2045CT（45V/20A，TO-220）**，SS54 撐不住 11A 峰值 | 6 | [buy360-ic](https://shopee.tw/product/26672482/20975998419) $15/顆，內含兩顆共陰極二極體並聯即 20A，TO-220 直插好焊 |
| 5 | ✅ | 電解電容 | 4700µF / 25V（16×27mm）**集中並聯 18800µF**，非分散 | 4 | [祥昌電子](https://shopee.tw/product/27742636/3338460511) $30/顆。非低 ESR 品，但 4 顆並聯等效 ESR 降為 1/4，夠用 |
| 6 | ⬜ | 12V 電源 | 12V 5A DC 變壓器 + DC 母座 5.5×2.1 | 1 | 蝦皮搜「12V 5A 變壓器」 |
| 7 | ⬜ | 保險絲 | **T5A 慢熔**玻璃管 + 保險絲座、船型開關（快熔會被脈衝跳掉；電容組接在保險絲之後） | 各 1 | 同上店家湊單 |
| 8 | ✅ | 軸承鋼球 | **方案 B 改 9.5mm**（市售標準規格是 **9.52mm = 3/8"**，比設計大 0.025mm，對球心高度影響 <0.02mm 可忽略）。鐵磁性，勿買 304 不鏽鋼 | 2 包 | ⭐**蝦皮實查**：[鼎興科技五金 鋼珠全系列](https://shopee.tw/product/6208068/13819042289) 選「**9.52mm(3/8") 50只**」$100，碳鋼、台灣製 ROHS、5.0 分、**8/5–8/6 到**。標題「可被磁鐵吸附本身不附磁性」正合需求（能被吸、不殘磁）。備選 Gcr15 G10 級：[甄甄五金行](https://shopee.tw/product/753006011/29928077211) 9.525mm 100粒 $290，但出貨 2–10 工作日（8/14–8/22）較慢 |
| 9 | ✅ | 電阻 | 100Ω（閘極串聯＋IR LED 限流@3.3V）完整版 12 顆、10kΩ（閘極下拉，必要）4 顆、220Ω–1k（指示 LED，選配）4 顆；光電晶體側免電阻（內部上拉）。IR LED 若改 5V 供電限流換 180–220Ω | 電阻包已有，挑出即可 | my_car 有電阻包 |
| 10 | 🔶 | 萬用板/線材 | v2 改**單片大板**：洞洞板雙面 7×9cm ✅、多芯線 24AWG 紅/黑 ✅（訊號線）／排針 ⬜、矽膠線 18AWG ⬜（線圈走大電流） | 1 批 | 祥昌電子（已購部分）；排針與 18AWG 待補 |

## ✅ 已下單（2026-08-03，4 筆訂單皆「待出貨」，總付款 $953）

| 訂單 / 賣場 | 品項 | 數量 | 訂單金額 | 預計到貨 |
|---|---|---|---|---|
| [鼎興科技五金](https://shopee.tw/product/6208068/13819042289) | 鋼珠 9.52mm(3/8") 50 只／包 | 2 包 | **$200**（免運） | 8/5–8/8 |
| [Mr. ADAPUTA](https://shopee.tw/product/71613488/27211691243) | 漆包線 #25/0.5mm 100g | 2 捲 | **$330**（免運） | 8/5–8/9 |
| [祥昌電子](https://shopee.tw/product/27742636/29053212103) | 3mm 940nm 發射器 ×8、[光敏接收器](https://shopee.tw/product/27742636/29053212103) ×8、[4700µF/25V](https://shopee.tw/product/27742636/3338460511) ×4、[洞洞板雙面 7×9](https://shopee.tw/product/27742636/22434454270) ×1、[多芯線 24AWG 5M](https://shopee.tw/product/27742636/6136173998) 紅／黑各 1 | 6 品項 | **$288**（免運） | 8/6–8/10 |
| [buy360-ic](https://shopee.tw/product/26672482/20975998419) | MBRF2045CT 45V/20A TO-220 | 6 顆 | **$135**（含運 $45） | 8/5–8/8 |

```
商品總金額  $908
運費總金額  $180
運費折抵   -$135   （祥昌／鼎興／ADAPUTA 三家皆達店取 $199 免運）
總付款金額  $953
```

寄送方式：全部蝦皮店到店。付款：貨到付款。

**這批到貨即可完成試配塊的全部 8 項實測。**

### 仍未購（皆非試配階段所需）

| 品項 | 狀況 |
|---|---|
| **MOSFET ×6** | ✅ 已完成候選調查（見下節）。**更正上一輪結論：台灣現在有現貨**，IRLB8721 與 IRLZ44N 皆 8/5–8/7 到。 |
| 12V 5A 電源 + DC 母座 | ✅ 已完成候選調查 |
| T5A 慢熔保險絲 + 座 + 船型開關 | ✅ 已完成候選調查（保險絲有規格陷阱，見下節） |
| 排針、18AWG 矽膠線（線圈大電流） | ✅ 已完成候選調查（矽膠線用量待定） |

**採購時機建議**：以上都屬 Phase 1 電路階段才用得到。
**建議等試配結果出來再下單**——若試配發現機構問題導致設計調整，電路規格可能連帶改變，
提早買反而可能買錯。台灣現貨 2 天到，等試配結果再下單不會拖到進度。

---

## Phase 1 電路料候選調查（2026-08-03，只調查未下單）

### 篩選條件修正紀錄

原訂條件 `Rds(on)@4.5V <15mΩ` **已作廢**。理由：實際佔空比只有 1.03%
（脈寬 6–16ms 隨速度變，但繞行一圈時間同步變化，兩者抵消），
11A、TO-220 無散熱片（Rth_ja≈62°C/W）下：

```
Rds(on) 16mΩ → 溫升 1.2°C
        30mΩ → 溫升 2.3°C
        50mΩ → 溫升 3.9°C
```

**Rds(on) 在本應用不是限制因素**，原門檻是照搬一般功率應用的直覺。
真正該卡的是 **Vgs(th) max** —— Vgs 不足導致半導通時 Rds(on) 會跳到歐姆級，那才是燒毀主因。

**修正後條件**：硬條件 = TO-220 直插 + Vds ≥30V + Id ≥20A + **Vgs(th) max ≤2.5V**；
軟條件 = Rds(on)@4.5V ≤30mΩ；加分 = datasheet 有標 @2.5V／@3.0V 等低壓 Rds(on)
（代表原廠真的驗證過低壓驅動）。

### MOSFET ×6 候選比較

| 料號 | Vgs(th) max | Rds(on)@4.5V | 最低標示 Vgs | Qg | 賣場 | 單價 | ×6 | 交期 | 賣場可信度 | 判定 |
|---|---|---|---|---|---|---|---|---|---|---|
| **IRLZ44N** | **2.0V** | ~30mΩ（@5V 25、@4V 35 內插） | 4.0V→35mΩ | 66nC | [傑森創工](https://shopee.tw/product/20917936/23024196080)（台北中山） | $25 | **$150** | **8/5–8/7** | **9 年店／4.2 萬評價；本品 93 評價、已售 1000+** | ⭐ **綜合首選** |
| IRLB8721PBF | 2.35V | 16mΩ | 4.5V | **7.6nC**（最小） | [久久工坊](https://shopee.tw/product/125966559/52609680201)（新北樹林） | $48（買 4–8 件 **$45**） | $270 | **8/5–8/7** | 7 年店／1084 評價；本品僅 1 評價、已售 22 | 原訂料號，規格最平衡 |
| IRF3708 | **2.0V** | 13.5mΩ | **2.8V→29mΩ**（唯一標低壓） | 24nC | [欣欣科技](https://shopee.tw/product/175283321/55511703605)（桃園蘆竹）／貨種「國產小芯片」 | $39 | $234 | 8/14–8/22 | ⚠️ **0 評價／0 已售** | 規格第一、**貨源最差** |
| IRLB3034PBF | 2.5V（卡上限） | **2.0mΩ**（最低） | 4.5V | **162nC**（最大） | [欣欣科技](https://shopee.tw/product/175283321/57161512578)（桃園蘆竹） | $42 | $252 | >7 天 | 5 評價 | 電氣最強但 Qg 最大 |
| ~~IRL3803~~ | **datasheet 無 max 值** | 9mΩ | 4.5V | 140nC | — | — | — | — | — | ❌ **排除**：Vgs(th) 只標 min 1.0V、Max 欄空白，無法驗證硬條件 |
| ~~AOD4184~~ | — | — | — | — | — | — | — | — | — | ❌ **排除**：AOD 前綴 = TO-252(DPAK) 貼片，無 TO-220 版本（AOT4184 不存在） |

**選型理由**：IRLZ44N 以「規格達標 + 賣場可信度壓倒性 + 最便宜 + 最快到」勝出。
Vgs(th) max 2.0V 比原訂 IRLB8721 的 2.35V 對 3.3V 驅動更安全，Rds(on) ~30mΩ 溫升僅 2.3°C。
IRF3708 規格最優（唯一有 @2.8V 保證）但唯一台灣貨源是 **0 評價的「國產」副廠**——
選它的理由正是原廠 datasheet 的低壓保證，買副廠等於失去該保證，自相矛盾，故不推薦。

⚠️ **選購陷阱**：搜尋 IRLZ44N 會大量混入 **IRFZ44N**（差一個字母 L）。
IRFZ44N 的 Vgs(th) 為 2–4V，**非 logic level，3.3V 驅動會半導通燒毀**。下單前務必逐字核對料號。

### 其他電路料候選

| 品項 | 推薦 | 單價 | 賣場 | 交期 | 淘汰的選項與理由 |
|---|---|---|---|---|---|
| 12V 5A 電源 | [台達電 Delta 原廠](https://shopee.tw/product/313943912/45003887405) 12V 5A（5.5×2.1 通用） | $159 | 台北中山／350 售、4.9 | 8/5 | 祥昌同款 **$329**（選 5A 後才顯示，$89 是 1A 價）貴一倍；虎尾 $297 且接頭 5.5×**2.5** 不合；[板橋 $90](https://shopee.tw/product/18364798/1856376942)（4000+ 售）與 [台中 $70](https://shopee.tw/product/17501736/21494735252) 更便宜但非品牌、需再確認接頭 |
| DC 母座 5.5×2.1 | [祥昌](https://shopee.tw/product/27742636/6448855355) 帶螺紋配螺母 | $8 | 祥昌／1000+ 售 | 8/5–8/7 | 規格直接對上，無需比較 |
| **T5A 慢熔保險絲** | [彰化 Time-Lag 延遲型](https://shopee.tw/product/78246604/22680950485) 選 **20mm_5A** | **$8** | 彰化／5000+ 售、208 評價 | 8/5–8/6 | ⚠️ **祥昌沒有 5A**：其 5×20 慢熔玻璃管只有 30A 單一規格；其 3.6×10 陶瓷絲既非玻璃管、未標慢熔、且**裝不進 20mm 保險絲座** |
| 保險絲座 | [祥昌 20mm 雲母型](https://shopee.tw/product/27742636/7037344005) | $11 | 祥昌／1000+ 售 | 8/5–8/7 | 或 [MT899 20mm 座](https://shopee.tw/product/26028424/10502577494) $16（565 售）。**20mm 座必須配 5×20mm 絲** |
| 船型開關 | [祥昌 2P2S ON/OFF 有段](https://shopee.tw/product/27742636/27607690658) | $22 | 祥昌／1000+ 售 | 8/5 | 開關位於電源入口、承受平均電流（佔空比 1%），一般 6A 規格即足夠 |
| 排針 2.54mm 單排 | [祥昌 台灣製](https://shopee.tw/product/27742636/10813415362) 選 **2.54排針 40PX1 (短)180°** | $20 | 祥昌／4000+ 售 | 8/5–8/7 | 同商品另有 1.27／2.0mm 與雙排，選錯間距無法用 |
| 18AWG 矽膠線 | [祥昌 UL3239](https://shopee.tw/product/27742636/23268803725) 紅／黑分開計價 | **$15／米** | 祥昌／297 評價 | 8/5–8/7 | ⚠️ **按米零剪，用量待定**（見下） |

### 定案

- **MOSFET：IRLZ44N ×6**（傑森創工 $25，$150）。ERA 驗算確認全數達標，
  Qg 66nC 在串 100Ω 時閘極尖峰 33mA（ESP32 安全）、開關 2.0µs 佔 6ms 脈寬 0.033% 可忽略。
  流通量極大的老料號、不易買到假貨，是額外優點。
- **18AWG 矽膠線：紅黑各 2m**。依據：直線段中心線離原點 115mm、驅動板 64×44 置中，
  板邊到線圈直線距離 8.3cm，繞行與彎曲餘裕取 20cm/條 →
  紅（+12V 側 ×4 ＋電源入線）110cm、黑（汲極側 ×4 ＋GND 幹線）120cm，加裁切損耗 → 各 2m。

### 賣場分配：兩案比較

兩家都無法單獨買齊：**MT899 缺矽膠線**（只有一般 PVC 多芯線），**祥昌缺 T5A 保險絲**（只有 30A）。

**方案 A：MT899 一家全包**（18AWG 改用一般多芯線）

| 品項 | 單價 | 數量 | 小計 |
|---|---|---|---|
| [T5A 慢熔保險絲](https://shopee.tw/product/26028424/22020725894) 20mm_5A | $10 | 3（耗材，備用） | $30 |
| [保險絲座 20mm](https://shopee.tw/product/26028424/10502577494) | $16 | 1 | $16 |
| [船型開關 KCD4 20A](https://shopee.tw/product/26028424/18791165438) | $20 | 1 | $20 |
| [排針 2.54 單排](https://shopee.tw/product/26028424/980616905) | $8 | 1 | $8 |
| [DC 電源母座](https://shopee.tw/product/26028424/1120033174) | $10 | 1 | $10 |
| [18AWG **一般多芯線** 3米](https://shopee.tw/product/26028424/907876176) | $45 | 1 | $45 |
| [熱縮套管 φ1~φ20](https://shopee.tw/product/26028424/910728394) /米 | $10 | 2 | $20 |
| [銅柱 M3](https://shopee.tw/product/26028424/903080559) | $3 | 4 | $12 |
| [PVC 絕緣膠帶](https://shopee.tw/product/26028424/657691683) | $20 | 1 | $20 |
| | | **小計** | **$181** |

差 $18 達免運，補 1 米熱縮或數顆銅柱即過。**未找到 M3 螺絲與束線帶，需另尋。**

**方案 B：祥昌湊免運 ＋ MT899 保險絲單**

| 品項 | 單價 | 數量 | 小計 |
|---|---|---|---|
| 排針 2.54排針 40PX1(短)180° | $20 | 1 | $20 |
| 18AWG **矽膠線** UL3239 紅／黑 | $15/米 | 各 2m | $60 |
| DC 母座 5.5×2.1 | $8 | 1 | $8 |
| 保險絲座 20mm 雲母型 | $11 | 1 | $11 |
| 船型開關 2P2S | $22 | 1 | $22 |
| ① [熱縮套管 2mm 黑](https://shopee.tw/product/27742636/5735610649) /米 | $7 | 3m | $21 |
| ② [銅柱 M3 細牙](https://shopee.tw/product/27742636/17791980547) | $2 | 4 | $8 |
| ② [M3 圓頭螺絲 SCR-1](https://shopee.tw/product/27742636/5548757500) 10入 | $15 | 1 | $15 |
| ③ [日洋 PVC 絕緣膠帶](https://shopee.tw/product/27742636/3361362712) | $19 | 1 | $19 |
| ③ [尼龍紮線帶 CU](https://shopee.tw/product/27742636/7436176027) | $20 | 1 | $20 |
| | | **祥昌小計** | **$204**（免運 ✅） |

MT899 另一單：保險絲 $10×3 = $30 ＋ 運費約 $45 = **$75**。**合計 $279。**

> ⚠️ 熱縮取 2m 時祥昌小計為 **$197，差 $2 達免運**——與上一輪祥昌卡在 $198 差 $1 同型。
> 熱縮改 3m（本來就會用到）即過門檻。

**兩案差 $80。唯一的實質規格妥協是線材**：

| | 矽膠線 UL3239 | 一般 PVC 多芯線 | 本應用是否用得到 |
|---|---|---|---|
| 耐溫 | −60~200°C | 80~105°C | 佔空比 1%、每脈衝 0.08J，不接近上限 → **用不到** |
| 18AWG 載流量 | 約 10–16A | 約 10–16A | 兩者皆滿足 11A 峰值 → **平手** |
| 耐反覆彎折 | 極柔軟、可承受數萬次 | 較硬 | **v2 是固定裝置，線接好就不動**，只有組裝／維修拆裝，數十次等級 → **用不到** |
| 剝皮／服貼性 | 較好 | 較差 | 手工焊接舒適度，非可靠度 |

矽膠線的優勢集中在「會動的部位」——機器人關節、移動軸、來回擺動的線束。
v2 沒有這種需求，**一般 PVC 多芯線在本應用沒有實質劣勢**。
此為「可將就」的差異，不同於保險絲慢熔那種「不能將就」的規格。

### 方案排序（ERA 判定）：C > A > B

- **C 最佳**——不妥協線材、省下 MT899 的運費，唯一成本是跑一趟買一個通用耗材。
- **B 最差**——多花 $80 只為換矽膠線，而矽膠線的優勢本應用用不到。
- **M3 螺絲與束線帶不影響方案**：五金行、大創、文具店都有，順手帶即可，
  不值得為它們多開一單。

### ✅ 定案：方案 C（David 2026-08-03 確認）

David 願意就近購買 T5A 慢熔保險絲，因此**全部集中祥昌一單免運**，線材維持原規格的矽膠線。

| 賣場 | 內容 | 商品 | 運費 | 小計 | 到貨 |
|---|---|---|---|---|---|
| 祥昌電子 | 排針、矽膠線紅黑各 2m、DC 母座、保險絲座、船型開關、熱縮套管 3m、銅柱 M3 ×4、M3 螺絲、絕緣膠帶、紮線帶 | $204 | **$0** ✅ | **$204** | 8/5–8/7 |
| 傑森創工 | MOSFET **IRLZ44N ×6** | $150 | $45 | **$195** | 8/5–8/7 |
| 台達電賣場 | 12V 5A 電源（5.5×2.1） | $159 | $45 | **$204** | 8/5 |
| David 自購 | T5A 玻璃管慢熔保險絲（實體電料行）、M3 螺絲與束線帶順手帶 | 約 $10–20 | — | — | — |

**線上實付約 $603**（商品 $513 ＋ 運費 $90）。

**後兩家為何不湊到免運**——兩條路都算過，都不划算：

1. **買湊單品**：傑森創工可湊的是麵包線 $55／麵包板 $25／Micro USB 供電 $15。
   但功率級走 11A，**麵包板接觸電阻大、額定僅 1–2A，線圈電流絕對不能上麵包板**；
   訊號級（4 MOSFET ＋ 4 二極體 ＋ 5 對 IR）又簡單到直接焊洞洞板比搭麵包板還快。
   → 真的用不到，依原則七不硬湊。
2. **換料號併單**：祥昌有含 IRL3705N 的混合型號商品 $35，併進祥昌就免運。
   但 $35×6 = $210 ＞ $25×6 ＋ 運費 $45 = $195，**單價差 $60 吃掉省下的 $45，淨虧 $15**，
   還要承擔規格未驗與選錯規格的風險。→ 維持 IRLZ44N。

> ⚠️ **尚未下單、未加入購物車**——等試配實測綠燈。
> 若試配結果導致機構調整、電路規格連帶改變，本清單需重新檢視。

### 兩項實查得到的技術確認

- **市售標準是 9.52mm（3/8"），不是 9.5mm**。比設計大 0.025mm →
  球心高度差 <0.02mm、孔心差 0.0125mm，皆可忽略，直接用。**不要買 9.0mm**（差 0.5mm 會讓球心低 0.35mm）。
- **祥昌的接收端是「光敏接收器」**（商品圖標示），即光電晶體／光敏二極體，
  不是 38kHz 解調接收頭 ✓ 符合我們「集極輸出＋內部上拉」的設計。
  （解調型只對調變光有反應，用於連續光遮斷偵測會失效——選購時要避開。）

### 二極體選型變更

原訂 SS54（5A/40V）撐不住 11A 峰值。改用 **MBRF2045CT（45V/20A，TO-220）**：
內含兩顆共陰極二極體，兩腳並聯即得 20A，遠超需求；TO-220 直插比 SS54 的 SMD 封裝好焊。

## 既有免購（已確認 2026-07-23）

- 烙鐵、焊錫、三用電表 ✅
- USB-C 線（XIAO ESP32-S3 供電/燒錄）✅
- 電阻包、XIAO ESP32-S3 Sense（my_car）✅

## 電路接法備忘（my_car 定稿，完整版見 `~/code/2026/my_car/docs/emring-driver.html`）

低邊開關：線圈上端 +12V、下端 MOSFET 汲極 D、源極 GND；飛輪二極體跨線圈（**陰極朝 +12V、陽極朝 D，接反直接燒**；
已改用 MBRF2045CT，TO-220 三腳為「陽極1／共陰極(中腳+散熱片)／陽極2」，**中腳接 +12V、兩側陽極併接後接 D** 即為 20A 並聯）；GPIO→22–47Ω→閘極，閘極對地 10k；IR 收端輸出 0–3.3V 勿拉 12V；ESP32 USB 供電、與 12V 共地、星狀接地防地彈跳誤觸發。起手脈寬 w≈1ms，IR 觸發→延遲 d→脈寬 w，由 ESP32 微調；同級兩道 IR 間距 s 測速 v=s/Δt。

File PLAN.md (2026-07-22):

# 電磁環形加速器 — 大致方案（v0.1，2026-07-22）

> **狀態（2026-07-22）**：老闆已核可。stl 已派工出試配塊；my_car 已交付單級估算與電路（`~/code/2026/my_car/docs/emring-driver.html`）：線圈 ≈1.5Ω/≈1mH、τ≈0.65ms、峰值 6–7A、起手脈寬 ≈1ms；**新增需求：12V 端並 2200–4700µF 低 ESR 電容供脈衝峰值**。採購依 [採購清單.md](採購清單.md) 由 David 下單。

原理研究見 [RESEARCH.md](RESEARCH.md)。本檔為整合 `stl`（3D 列印）與 `my_car`（既有硬體）兩個 session 回覆後的定案方向。

## 定案參數

| 項目 | 決定 | 依據 |
|---|---|---|
| 軌道 | 中心圓 Ø24cm、**一體列印**、PETG | H2D 實測可用 300×320；≤24cm 一體印可避免接縫（鋼球高速跑圈對 0.1mm 凸緣敏感）；PLA 55°C 會軟，線圈周邊一律 PETG |
| 線圈段數 | 4 段均布 | 入門夠用，電路複製 4 份 |
| 線圈隧道 | C 形斷面（底部開縫）、壁厚 0.8mm、內徑 14.5mm | stl 建議：球持續滾在軌道面不換面、磁隙最小化；0.4 噴嘴 2 週線立印可行 |
| 鋼球 | 12.7mm（1/2"）軸承鋼球（鉻鋼，鐵磁性） | 需採購 |
| 漆包線 | 0.5mm，繞線層厚 4mm（約 8 層 × ~36 匝 ≈ 280–300 匝） | bobbin 外徑據此定，給 stl 出參數化模型 |
| 感測 | 分立 940nm IR LED + 光電晶體「對射」，裝軌道兩側預留孔（隧道入口前） | ITR9608 槽寬僅 5mm，跨不過 15mm 軌道，不採用 |
| 控制 | XIAO ESP32-S3（my_car 現有）：讀 4 路 IR、出 4 路脈衝，時序軟體可調＋順帶測速 | 比純硬體版好調 suck-back 時機；3.3V logic |
| 功率級 | IRLB8721（3.3V 閘極可驅動）× 4 + SS54 蕭特基飛輪二極體 × 4 | IRLZ44N 在 3.3V 驅動不足，不選 |
| 電源 | 12V 5A DC + 總開關 + 5A 保險絲；ESP32 走 USB 或 buck | 低壓安全；防線圈連續通電過熱 |

## 給 stl 的三個開工數字

- 中心圓直徑：**240mm**
- 線圈段數：**4**
- 線徑/繞線層厚：**0.5mm / 4mm**（bobbin 內徑 14.5、壁 0.8、兩端法蘭、繞線起止孔+出線槽）
- IR 感測孔：**要預留**，隧道入口前軌道兩側 Ø3mm 對射孔，建議沿軌道方向多留 2–3 組孔位供時機微調

## 採購清單（my_car 盤點後的缺件）

- [ ] 漆包線 0.5mm × 100g
- [ ] IRLB8721 × 6（含備品）
- [ ] 940nm IR LED + 光電晶體 × 6 對
- [ ] SS54 蕭特基二極體 × 6
- [ ] 12V 5A 電源 + DC 母座 + 開關 + 保險絲座(5A)
- [ ] 軸承鋼球 12.7mm × 5
- [ ] 萬用板、排針、矽膠線
- [ ] 烙鐵/焊錫/三用電表 — 桌上是否已有待確認

既有可用：電阻包、XIAO ESP32-S3 Sense（my_car）；my_car 並可支援線圈匝數計算與驅動電路圖。

## 階段

1. **Phase 1 — 單級直線驗證**：印短直軌 + 1 個 bobbin（先印 stl 的試配塊），繞一顆線圈、焊一組驅動，用 ESP32 調通「擋光通電→過中心前斷電」時序。
2. **Phase 2 — 環形整合**：Ø24cm 一體軌道 + 4 線圈 + 底座，逐級點亮。
3. **Phase 3 — 玩具化**：測速顯示、外殼修飾、（選配）速度上限保護。

## FDM 配合鐵律（stl 交代）

名義間隙 ≥0.5mm；先印小試配塊再印大件。

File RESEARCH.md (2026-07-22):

# 電磁環形加速器（Electromagnetic Ring Accelerator）研究筆記

科學玩具目標：鋼球在環形軌道上，經過線圈加速段被電磁力加速，繞一圈回到原點再次加速，持續循環直到達到飽和速度。

## 一、基本原理

這類裝置的本質是「磁阻式線圈砲（reluctance coilgun）」的環形循環版：

1. **吸引加速**：線圈通電產生磁場，鐵磁性鋼球被吸向線圈中心（磁阻最小位置），過程中被加速。
2. **關鍵時機（suck-back 問題）**：球一旦越過線圈中心，同一個磁場會反過來把球往回拉、變成減速。所以必須在球到達線圈中心「之前或恰好抵達時」斷電，讓球靠慣性衝出去。
3. **感測觸發**：用紅外線對射管（IR LED + 光電晶體）或霍爾感測器偵測球接近，觸發 MOSFET 讓線圈通電；球離開感測區即斷電。**感測器與線圈中心的相對位置就是時機控制**——調整幾何位置即可調整通電/斷電時機，最簡版本完全不需要微控制器。
4. **循環加速**：球每經過一次線圈就獲得一點動能，繞圈回來再加速。當單圈獲得的能量 = 滾動摩擦 + 空氣阻力 + 渦流/磁滯損耗時，達到飽和速度。

市售同類產品（可當參考範本）：多為 4–6 組線圈均布在直徑 16–25cm 的環形軌道上，12V 低壓供電，每組線圈配獨立的感測+驅動小電路板。

## 二、系統組成

```
[12V 電源] ──> [每線圈一組驅動電路] ──> [線圈] ──> 鋼球
                     ↑
              [IR 對射感測器]（球擋光 → 觸發）
```

### 1. 機構（3D 列印）
- **環形軌道**：U 型或 V 型凹槽，外側要有擋牆（離心力會把球往外推）。建議軌道中心圓直徑 20–30cm，太小則離心力損耗大。
- **線圈加速段**：軌道在此變成一小段「隧道」，外面繞線圈。此段管壁越薄越好（磁隙越小力越大），內徑比球徑大 1–2mm。**線圈附近不可用鐵磁性螺絲或金屬件**。
- **線圈骨架（bobbin）**：可設計成獨立列印件，繞好線再卡進軌道，方便重繞調整。
- **底座**：固定軌道、藏電路板與走線。
- 材料 PLA 或 PETG 皆可（線圈 duty cycle 低、發熱有限）。

### 2. 線圈
- 漆包線 **0.4–0.6mm**（約 AWG 23–26），每個線圈約 **200–400 匝**、繞 3–6 層。
- 線圈軸向長度約等於球直徑（1–1.5 倍），太長會讓斷電時機難抓。
- 12V 下目標電阻約 1–3Ω → 瞬間電流 4–10A（脈衝式，平均功率不高）。
- 匝數多 → 力大但電感大、磁場建立慢，會限制高速時的效果；這是主要需要實驗調整的參數。

### 3. 鋼球
- 直徑 10–15mm 的**軸承鋼球**（chrome steel）最理想。
- ⚠️ 不鏽鋼要挑 420/440 系（鐵磁性）；**304 不鏽鋼不會被磁鐵吸，不能用**。
- 球跑久了會殘磁，可多備幾顆或準備消磁器。

### 4. 感測 + 驅動電路（每線圈一組，免 MCU 版本）
| 元件 | 規格建議 | 作用 |
|---|---|---|
| IR 對射管 | ITR9608 槽型光遮斷器，或分立 940nm IR LED + 光電晶體 | 偵測球進入 |
| N-ch MOSFET | logic-level，如 IRLZ44N、IRLB8721 | 開關線圈大電流 |
| 飛輪二極體 | 1N5408 或 SS54（蕭特基），跨接線圈 | 吸收斷電時的反電動勢突波，保護 MOSFET |
| 前級電晶體/比較器 | 2N2222 或 LM393 | 把感測訊號整形後推動 MOSFET 閘極 |
| 電阻若干 | IR LED 限流、閘極電阻 100Ω、閘極下拉 10kΩ | — |
| 指示 LED（選配） | 每次觸發閃一下 | 除錯直覺 |

- 電源：**12V DC 5A** 變壓器（安全低壓；想更猛可上 24V，但 MOSFET 與線圈要重算）。
- 進階版：改用 Arduino / 555 控制脈衝寬度與延遲，可精細調時序、做速度顯示（再加一組 IR 對管當測速門）。

### 5. 焊接工具
電烙鐵、萬用板（洞洞板）或自製 PCB、杜邦線/矽膠線、三用電表（必備，量線圈電阻與檢查短路）。

## 三、設計要點與陷阱

1. **時機就是一切**：感測器放在線圈入口前方，球「擋光期間通電、離開光路斷電」。斷電點要落在球心到達線圈中心之前。做成可滑動微調的感測器座會省很多事。
2. **先做直線單級原型**：先 3D 列印一段直軌 + 一個線圈 + 一組電路，在桌上驗證能把球打出去、調好感測器位置，再複製成環形多級。這是最重要的開發策略。
3. **高速後時機會漂移**：球越快，磁場建立時間（L/R 時間常數，約幾 ms）相對越吃緊，這決定了飽和速度。線圈不要繞太多匝。
4. **離心力與軌道**：外牆要夠高；U 槽接觸面越光滑摩擦越小（列印後可輕微打磨或選擇讓球走兩條稜線的 V 槽減少接觸面）。
5. **安全**：12V 本身安全，但線圈瞬間電流大——電源要能扛突波、線圈連續通電（球卡住、感測器誤觸發）會發熱，最好在電源端加保險絲（3–5A）與總開關。斷電突波一定要有飛輪二極體。
6. **殘磁與磁化**：線圈斷電後的殘磁與球本身被磁化都會造成拖曳，蕭特基飛輪二極體讓磁場衰減快一點；也有人串小電阻加速放電（代價是突波電壓變高）。

## 四、建議 BOM（4 線圈版粗估）

- 漆包線 0.5mm × 100g 一捲
- 軸承鋼球 12.7mm（1/2"）× 5 顆
- IRLZ44N × 4、ITR9608 × 4（多買備品）
- 1N5408 × 4、2N2222 × 4、電阻包
- 萬用板、排針、線材
- 12V 5A 電源 + DC 母座 + 開關 + 保險絲座
- 3D 列印：軌道分段（拼接）、線圈骨架 × 4、底座

## 五、開發階段規劃

1. **Phase 1 — 單級直線原型**：一個線圈 + 一組電路 + 直軌，驗證加速與時機調整。
2. **Phase 2 — 環形軌道**：設計可拼接的環形軌道與線圈段，先裝 2 個線圈讓球能穩定繞圈。
3. **Phase 3 — 完整版**：4–6 線圈、整合底座與電路、加測速顯示（選配）。

## 參考資料

- 市售 6 線圈環形加速器（規格參考）：https://www.enginediy.com/products/stark-6-coils-ring-accelerator-cyclotron-high-tech-physics-model-1
- Amazon 同類 DIY 套件（原理說明）：https://www.amazon.com/Electromagnetic-Accelerator-Induction-Circular-Experiment/dp/B0F5HBPWDP
- 線圈砲電路教學（thyristor/MOSFET 驅動、IR 觸發）：https://electronoobs.com/eng_circuitos_tut74.php
- GaussGun 工程專案（電路細節）：https://www.instructables.com/GaussGun-Coil-Gun-Electronics-and-Engineering-Proj/
- 彈珠加速器討論串（感測與驅動方案）：https://forum.allaboutcircuits.com/threads/marble-accelerator-for-game-room.209642/

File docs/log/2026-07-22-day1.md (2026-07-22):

# 開發日誌 Day 1（2026-07-22）：從一句構想到「零件到手即可開測」

> 這篇是部落格素材原稿，記錄專案第一天的完整過程。

## 起點

構想只有一句話：「金屬球經過電磁加速裝置往前跑，在環形軌道繞一圈回到原點重新加速」——做成科學玩具，3D 列印外框、自己繞線圈、自己焊電路。

## 原理研究

查了市售同類產品與 coilgun 開源專案後確認核心原理：**磁阻式線圈砲**。線圈把鋼球吸向中心加速，但球一過中心就會被反向拉住（suck-back），所以「在對的時機斷電」是整個專案的靈魂。用 IR 對射管偵測球、MOSFET 開關線圈，感測器與線圈的相對位置＋脈衝寬度就是全部的時機控制。

## 一天內定案的方案

- **機構**：Ø240mm 環軌一體列印（避免接縫，鋼球高速對 0.1mm 凸緣敏感）、PETG、4 線圈段、C 形薄壁隧道 0.8mm（磁隙每省 0.1mm 吸力都有感）、bobbin 一體含法蘭。
- **幾何巧思**：開放段球騎 45° 雙軌（球心高 9.98mm），進隧道改騎 bobbin 內孔底，孔心設 10.88mm 讓球心同高——過渡零落差。
- **電路**：IRLB8721 低邊開關（3.3V 可直驅）+ SS54 飛輪二極體 + XIAO ESP32-S3 時序控制。
- **供電陷阱**：脈衝峰值 6–7A 超過 12V/5A 電源——解法是線圈旁並 2200–4700µF 低 ESR 電容組供峰值、電源只補平均；保險絲要用慢熔 T5A（快熔會被脈衝跳掉）。

## 三個當天學到的工程亮點

1. **全速域電流飽和**：線圈 τ=L/R≈0.65ms，遠短於任何實用脈寬（2.3–19ms）→ 每級推力都接近上限，調校只需專心調關斷時機，完全不用管電流上升。
2. **脈寬對球速表**：w≈d_eff/v。0.5m/s 要 19ms、3m/s 只要 2.3ms——韌體的安全上限一開始設 3ms 差點把慢速段鎖死，靠 review 抓出來。
3. **失效模式是可以「選」的**：IR 光電晶體用集極輸出+內部上拉，遮光=HIGH——於是斷線、發射管失效都會讀 HIGH 而觸發保護停用（fail-safe）；如果選射極隨耦接法，斷線會被誤判成「有光」而漏檢。同一顆零件，接法決定失效時是安全還是危險。

## 目前狀態

試配塊 STL 已出圖（bobbin 薄壁樣 + 軌道弧段樣 + IR 孔樣）、驅動電路含 ASCII 電路圖定稿、P1 單級驗證韌體完成（含脈寬上限、防連發、卡球停用三道保護）。

下一步：列印試配塊 + 零件採購到貨 → Phase 1 單級直線實測。

## 幕後

這個專案由多個 Claude Code session 協作完成：本 session 統籌研究與整合、`stl` session 負責參數化 CAD 出圖、`my_car` session 負責電路估算與韌體 review，跨 session 用 tmux 互傳訊息。一天內從構想跑到 ready-to-build，包含兩輪互相抓錯的 review。

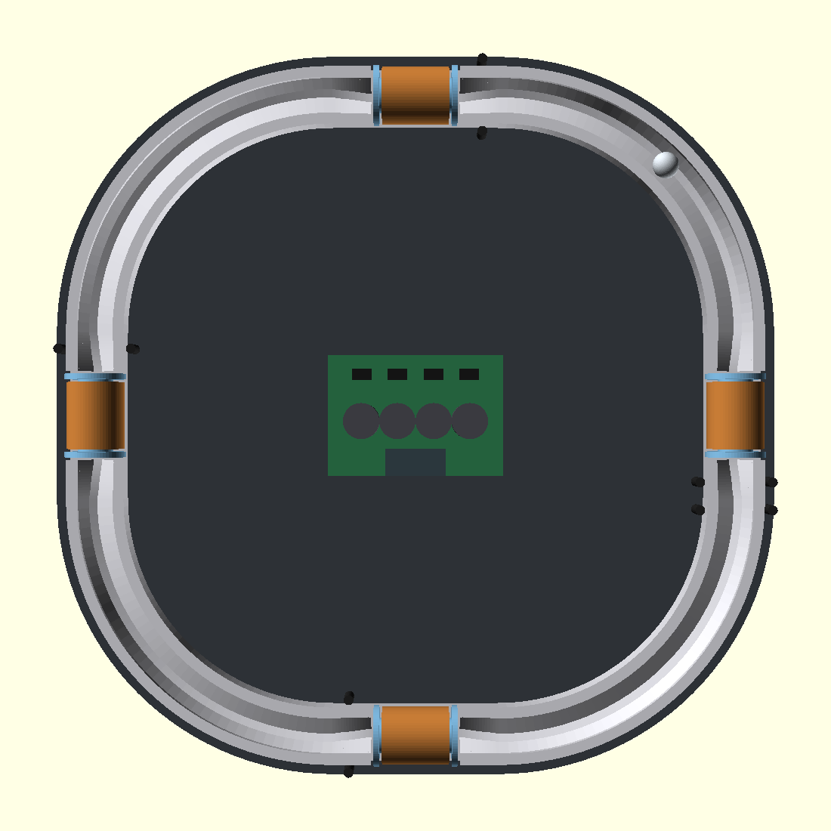
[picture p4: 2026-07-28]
docs/images/concept_v2_top.png

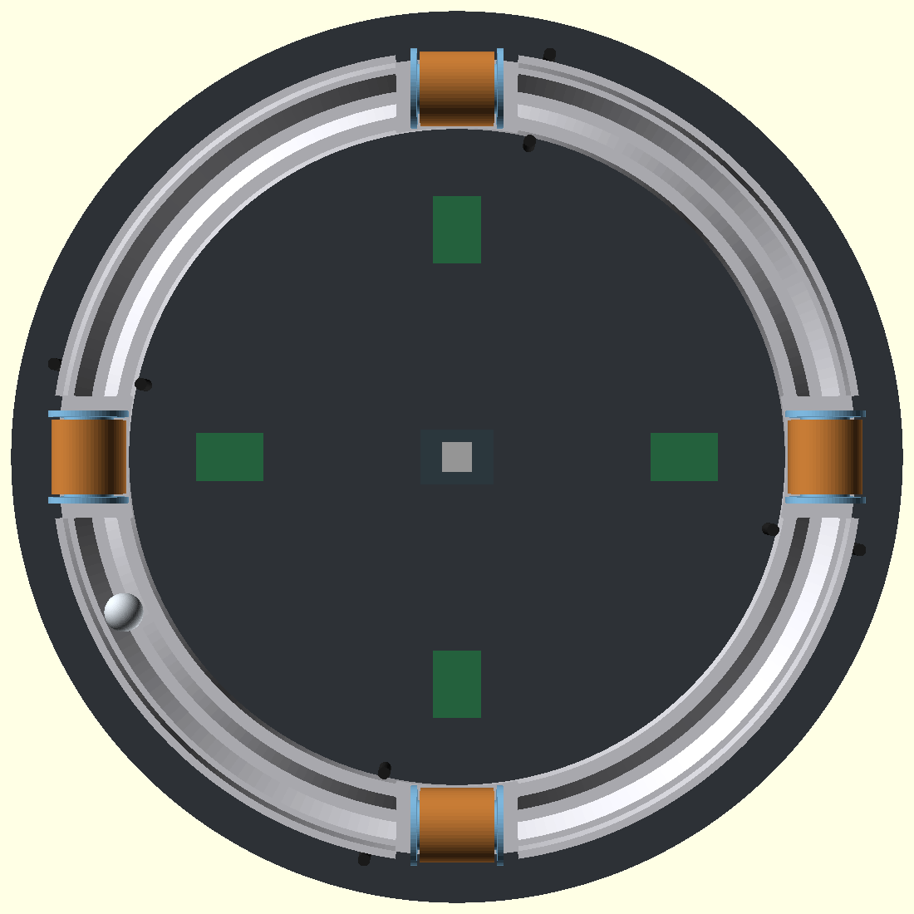
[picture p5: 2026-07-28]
docs/images/concept_v1_top.png

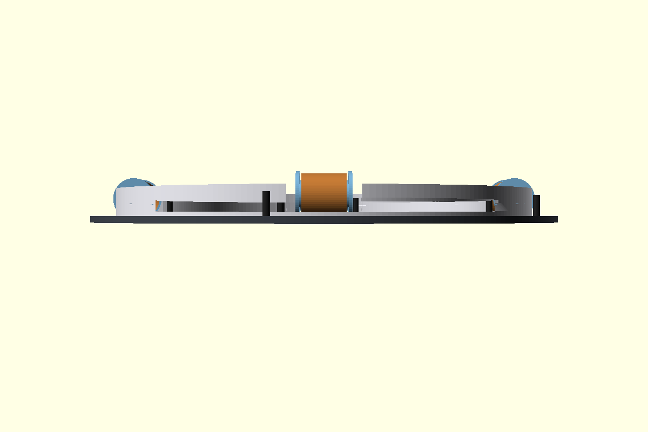
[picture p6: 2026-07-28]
docs/images/concept_v1_side.png

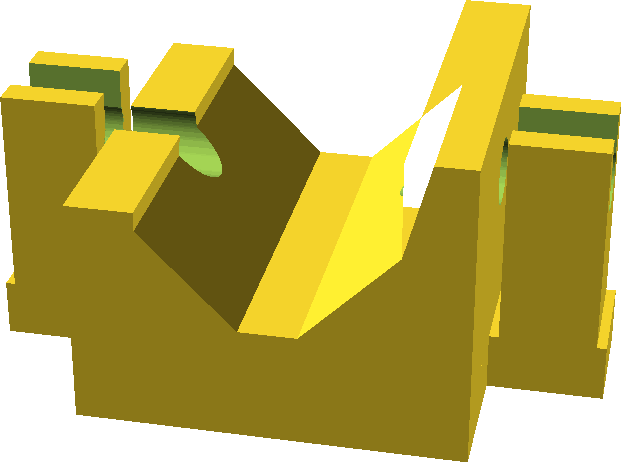
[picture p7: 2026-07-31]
hardware/preview/ir_clip.png

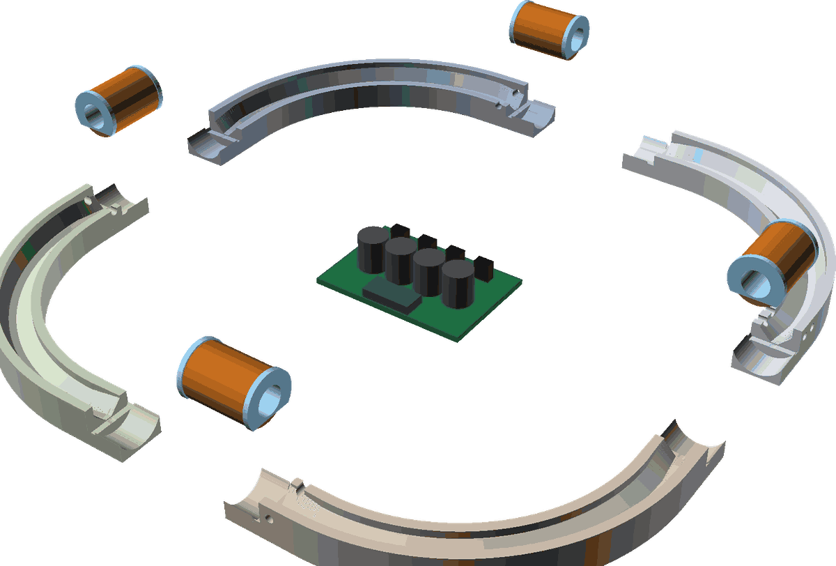
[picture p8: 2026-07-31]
hardware/preview/exploded.png

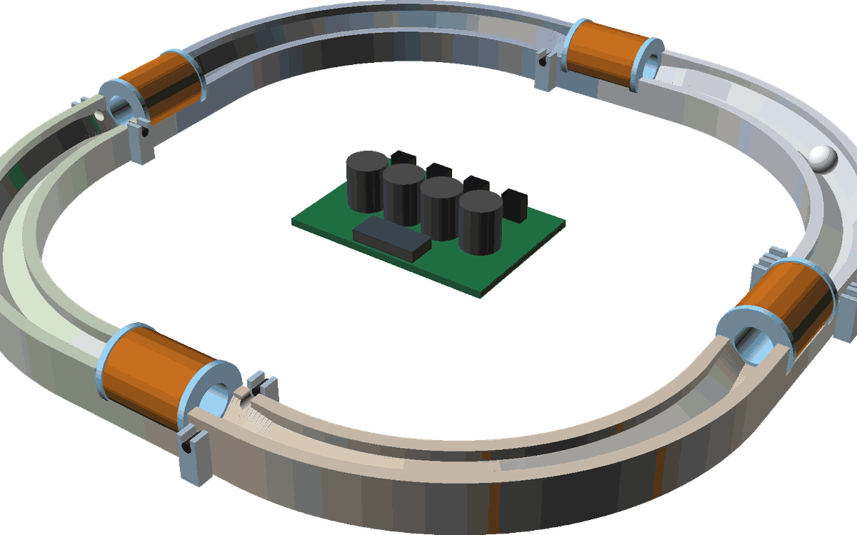
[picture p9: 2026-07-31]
hardware/preview/iso.png

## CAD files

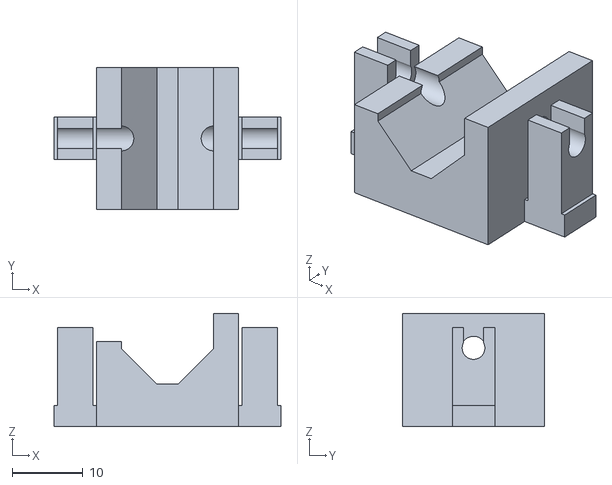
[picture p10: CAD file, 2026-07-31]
hardware/test-fit-v2/test_v2_ir.stl
32.0 x 20.0 x 16.0

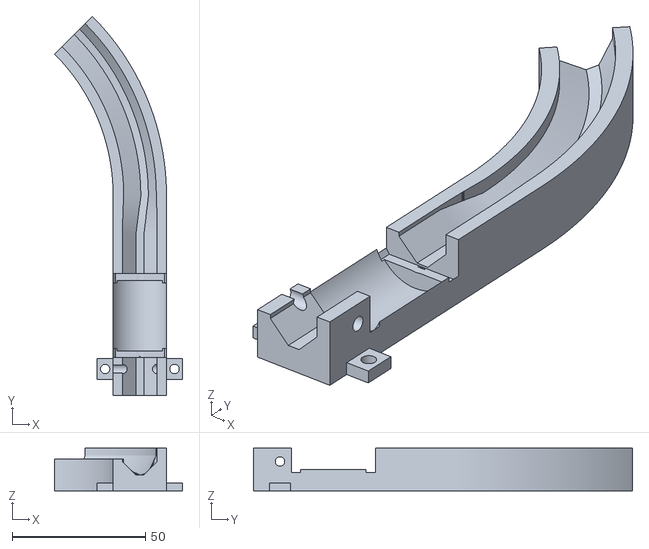
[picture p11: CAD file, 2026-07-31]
hardware/test-fit-v2/test_v2_combo.stl
48.0 x 142.2 x 16.0

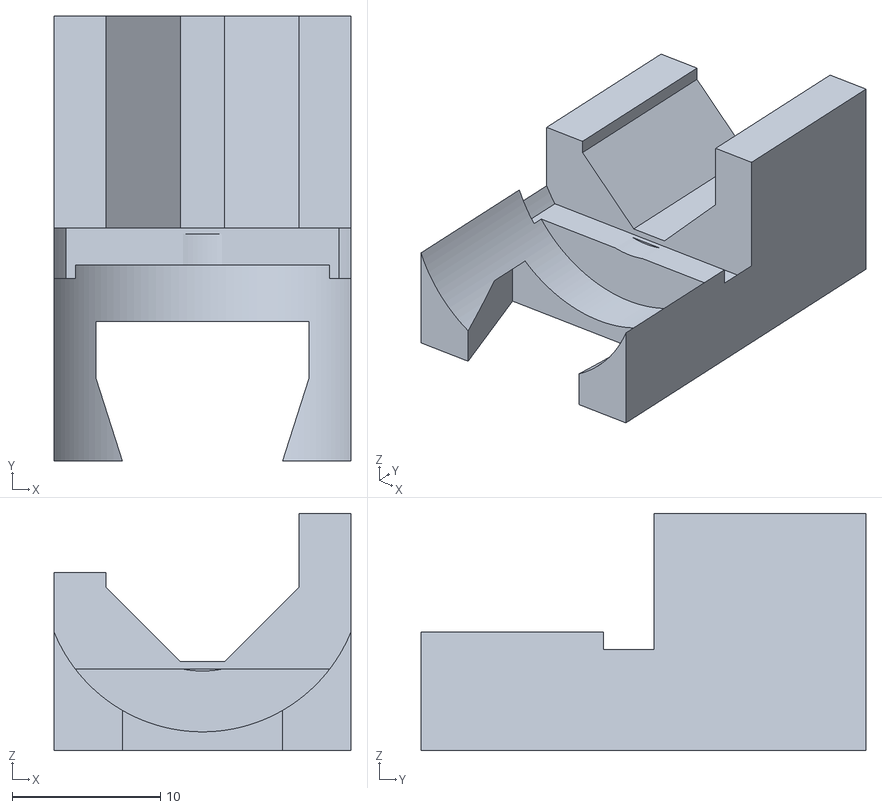
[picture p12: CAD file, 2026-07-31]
hardware/test-fit-v2/test_v2_joint_b.stl
20.0 x 30.0 x 16.0

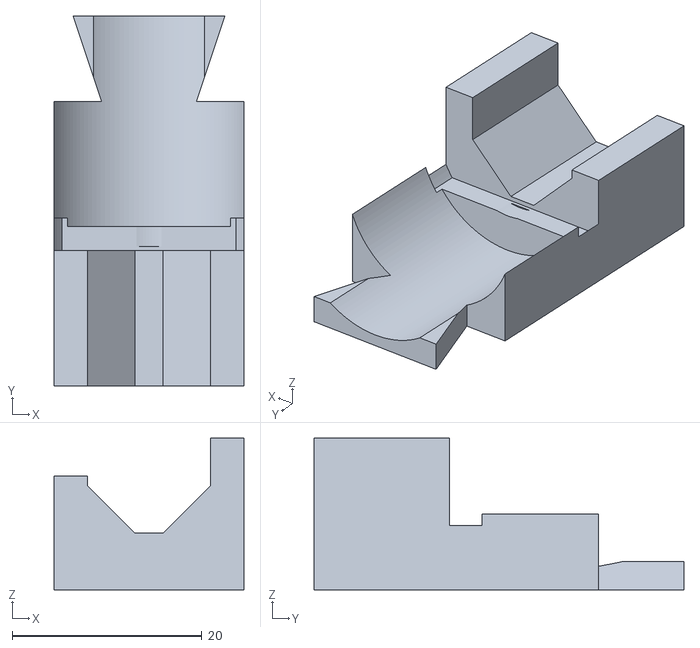
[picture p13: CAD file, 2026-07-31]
hardware/test-fit-v2/test_v2_joint_a.stl
20.0 x 39.0 x 16.0

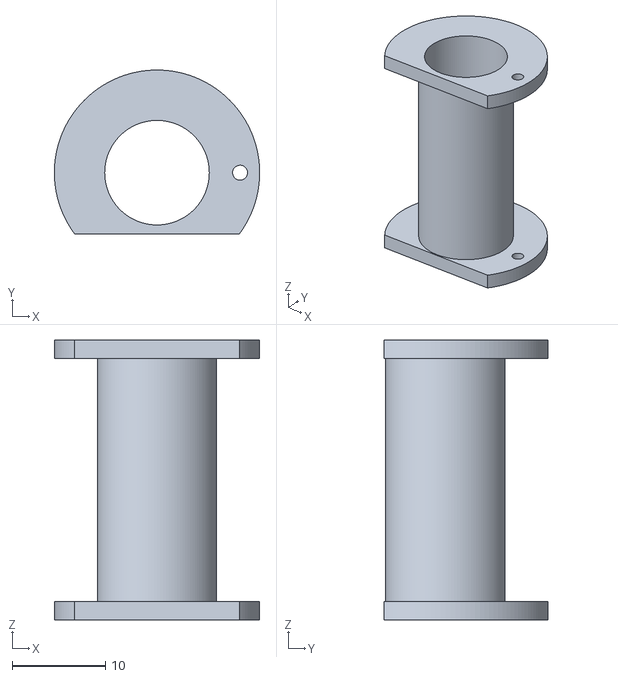
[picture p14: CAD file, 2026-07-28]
hardware/test-fit-v2/test_v2_bobbin.stl
22.0 x 17.6 x 30.0

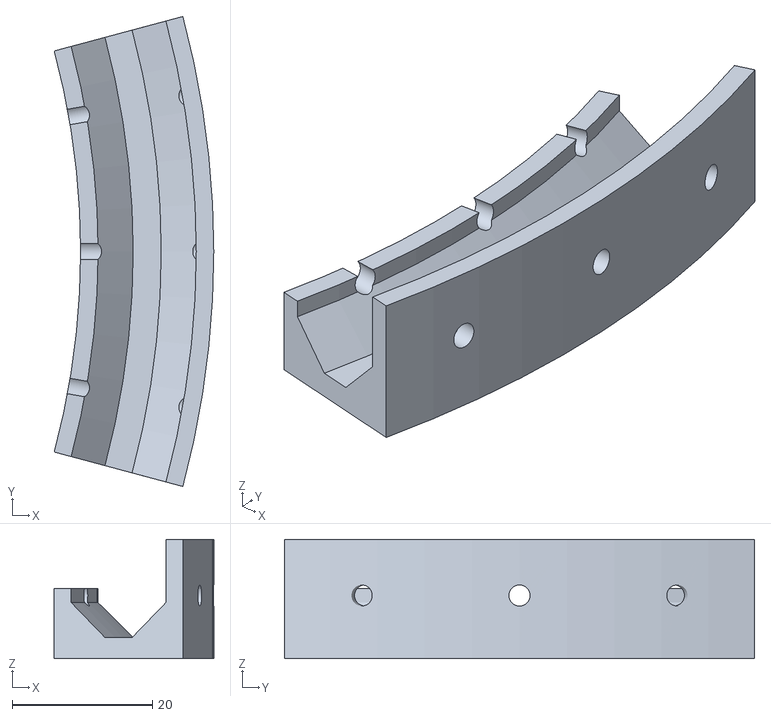
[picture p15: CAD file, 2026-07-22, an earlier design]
hardware/test-fit/test_track.stl
22.8 x 67.0 x 17.0

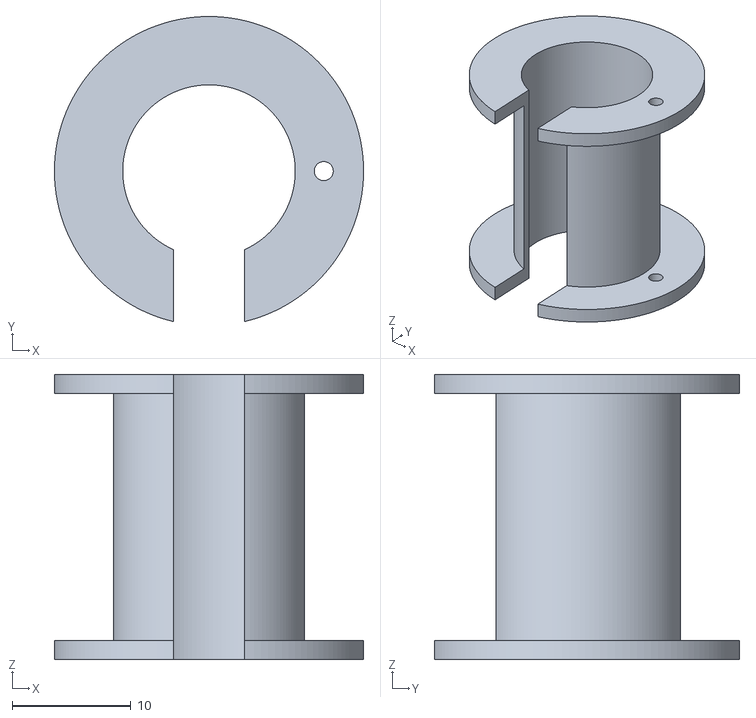
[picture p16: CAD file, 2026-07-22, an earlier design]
hardware/test-fit/test_bobbin.stl
26.0 x 25.6 x 24.0

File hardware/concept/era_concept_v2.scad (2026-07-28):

// 電磁環形加速器 — 方案 B（v2 Banked-Square 4）概念示意圖
// 與 v1 差異：圓角方形（線圈在直線段、入口角 0°）、彎道傾斜賽道 65°/25°、Ø9.5 小球
// 渲染：openscad -o concept_v2.png --preview era_concept_v2.scad

STRAIGHT = 60;      // 直線段長（中間 30 放線圈，兩端各 15 為 banking 漸變段）
R_CORNER = 85;      // 彎道中心線半徑
C = STRAIGHT/2;     // 彎心座標 (±30, ±30)
D = C + R_CORNER;   // 直線段中心線離原點距離 = 115

BALL_D  = 9.5;
BORE_D  = 11.2;     // bobbin 內孔
BASE_Z  = 3;        // 槽底基準面（幾何基準，不隨底板厚度改變）
// 底板全周 3→6：法蘭需要的是基準面「下方」的空間，側面加肉解不了；
// 只加厚線圈區則底面不平、253mm 大件貼床會翹 → 全周下移，底面維持同一平面。
// 幾何一律不動，只是底面從 z=0 下移到 z=−3。代價約 +58g，換整圈剛性。（stl 定案 2026-07-28）
PLATE_BOT = -3;
BALL_Z  = BASE_Z + 5.218;  // 球心高 = r√2 − 平底半寬 = 4.75×1.4142 − 1.5
// 球在隧道內是「躺在孔底」滾，不是懸在孔心 → 孔心必須抬高半個間隙，
// 球心才會與開放段同高。寫成 BORE_Z = BALL_Z 會讓球進隧道時跌 0.85mm。（stl 2026-07-28 抓出）
BORE_Z  = BALL_Z + (BORE_D - BALL_D)/2;   // = 8.218 + 0.85 = 9.068
BANK    = 20;       // 彎道傾斜角（外側面 45+20=65°、內側面 45−20=25°）

NSEG = 15;          // banking 漸變段分片數（示意用；正式件應以連續掃掠生成）

// ---- banking = 整個 V 槽「繞球心旋轉」，槽夾角維持 90° ----
// 關鍵：球心的高度與徑向位置全程不變 → 直線段↔彎道過渡零高差。
// （若改成單獨掰彎兩個面的角度，槽夾角會張開，球陷得較淺、球心抬高 3.3mm，過渡就會有坡。）
function rt(p, phi) = [ p[0]*cos(phi) - (p[1]-BALL_Z)*sin(phi),
                        BALL_Z + p[0]*sin(phi) + (p[1]-BALL_Z)*cos(phi) ];

module profile(t) {
  phi = BANK * t;
  a = rt([ 6.5, BASE_Z+5], phi);   // 外側 45° 斜面頂
  b = rt([ 1.5, BASE_Z  ], phi);   // 平底外緣
  c = rt([-1.5, BASE_Z  ], phi);   // 平底內緣
  d = rt([-6.5, BASE_Z+5], phi);   // 內側 45° 斜面頂
  polygon([[-10,PLATE_BOT], [10,PLATE_BOT], [10,13], [a[0],13], a, b, c, d, [d[0],9], [-10,9]]);
}

// ---- 直線段：中央 t=0，兩端漸變到 t=1 銜接彎道 ----
module straight_side() {
  translate([D,0,0]) rotate([90,0,0]) {
    translate([0,0,-15]) linear_extrude(30) profile(0);   // 中段：線圈區
    for (i = [0:NSEG-1]) {
      t0 = i/NSEG;  seg = 15/NSEG;
      translate([0,0,15 + i*seg])  linear_extrude(seg+0.01) profile(t0);
      translate([0,0,-15 - (i+1)*seg]) linear_extrude(seg+0.01) profile(t0);
    }
  }
}

module corner() {
  translate([C,C,0]) rotate_extrude(angle=90, $fn=160)
    translate([R_CORNER,0]) profile(1);
}

module track() {
  color("#d8d8de") difference() {
    union() {
      for (a=[0,90,180,270]) rotate([0,0,a]) { straight_side(); corner(); }
    }
    // 線圈段清出兩側牆（由 bobbin 隧道取代）
    for (a=[0,90,180,270]) rotate([0,0,a])
      translate([D,0,BASE_Z+10]) cube([26, 32, 20], center=true);
  }
}

// ---- 線圈組（bobbin 內孔 11.2、D 形法蘭 22×17.6、0.5mm×290匝 外徑約 20.8）----
// 圓法蘭 Ø22 的下緣落在 BORE_Z − 11 = −1.93，會伸進底板很深、逼出很薄的底膜。
// 解法（stl 定案）：法蘭下緣截平於基準面下 0.5（z=FLANGE_CUT），沉槽只需淺淺一道，
// 底膜回到 5.2mm。截平弦半寬 = √(11² − (BORE_Z−FLANGE_CUT)²) = 8.82 → 全寬 17.6。
FLANGE_CUT = BASE_Z - 0.5;   // = 2.5

module coil_section() {
  rotate([90,0,0]) {
    color("#7ab3d9") {
      difference() {
        cylinder(d=BORE_D+1.6, h=30, center=true, $fn=64);
        cylinder(d=BORE_D, h=32, center=true, $fn=64);
      }
      for (s=[-1,1]) translate([0,0,s*14]) difference() {
        cylinder(d=22, h=2, center=true, $fn=64);
        cylinder(d=BORE_D, h=4, center=true, $fn=64);
        // D 形截平：局部 −y 對應全域下方（本模組整體 rotate([90,0,0])）
        translate([-15, -(BORE_Z-FLANGE_CUT)-20, -3]) cube([30, 20, 6]);
      }
    }
    color("#c47a35") difference() {
      cylinder(d=20.8, h=24, center=true, $fn=64);
      cylinder(d=12.9, h=26, center=true, $fn=64);
    }
  }
}

// v2 感測：每級 1 道觸發 IR；其中一級（a=0）加第 2 道作測速基準
module ir_gate(a, y) {
  rotate([0,0,a]) for (side=[-1,1])
    translate([D + side*13, y, 0]) color("#222") cylinder(d=3.5, h=12, $fn=24);
}

// ---- 組立 ----
// 底座（圓角方形板，讓在軌道加厚後的底面 z=PLATE_BOT 之下）
color("#3a3f46") translate([0,0,PLATE_BOT-4]) linear_extrude(4)
  hull() for (sx=[-1,1], sy=[-1,1]) translate([sx*C, sy*C]) circle(r=R_CORNER+16, $fn=120);

track();

for (a = [0,90,180,270]) {
  rotate([0,0,a]) translate([D,0,BORE_Z]) coil_section();
  ir_gate(a, -24);                      // 每級觸發道
}
ir_gate(0, -34);                        // 基準級的第 2 道（測速）

// 集中驅動板：4× MOSFET + 4700µF×4 並聯 + XIAO ESP32-S3（坐在底座上）
translate([0,0,PLATE_BOT]) {
  color("#2e7d4f") translate([0,0,1]) cube([64,44,2], center=true);
  for (i=[-1.5:1:1.5]) color("#1a1a1a") translate([i*13, 15, 4]) cube([7,4,9], center=true);
  for (i=[-1.5:1:1.5]) color("#4a4a52") translate([i*13, -2, 8]) cylinder(d=13, h=14, center=true, $fn=32);
  color("#37474f") translate([0,-17,4]) cube([22,10,4], center=true);
}

// 鋼球在彎道上（球心高度與徑向位置和直線段完全相同）
rotate([0,0,45]) translate([C*sqrt(2) + R_CORNER, 0, BALL_Z])
  color("#cfd6dd") sphere(d=BALL_D, $fn=64);

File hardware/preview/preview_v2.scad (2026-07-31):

// ============================================================
// ERA v2 正式件「完成品」預覽（Banked-Square 4）
// 純視覺用途——幾何參數與 test_fit_v2.scad 同源，但不作為出圖檔。
// 用途：讓 David / ERA 在下正式件之前先看整體長相與分件方式。
//
// 渲染：
//   openscad -o preview_iso.png  --preview --autocenter --viewall --imgsize=1600,1200 \
//            -D 'view="iso"' preview_v2.scad
// view = iso | top | corner | section | explode | testfit
// ============================================================
view = "iso";
$fn = 64;

// ---- 幾何（與 test_fit_v2.scad 同源）----
BALL_D  = 9.5;
BASE_Z  = 3;                    // 槽底距「加厚底之上」的高
BALL_Z  = BASE_Z + 5.218;       // 8.218（局部）
BANK    = 20;
STRAIGHT = 60; R_C = 85;
C  = STRAIGHT/2;                // 30
DD = C + R_C;                   // 115：直線段中心線離原點
PLATE = 3;                      // 加厚底（全周，正式件定案）

BOB_ID = 11.2; BOB_WALL = 0.8; BOB_OD = BOB_ID + 2*BOB_WALL;
BOB_LEN = 30; FLANGE_D = 22; FLANGE_T = 2;
BORE_Z = BALL_Z + (BOB_ID-BALL_D)/2;   // 9.068
Z_CUT  = 2.5; FL_FLAT = BORE_Z - Z_CUT;
COIL_OD = 20.8; CRADLE_T = 2.7;
IR_D = 3.5; IR_Z = 8;
NSEG = 12;                      // 預覽用（出圖件是 30）

AXZ = PLATE + BORE_Z;           // 隧道軸心絕對高 12.068
BZ  = PLATE + BALL_Z;           // 球心絕對高 11.218

// ---- 剖面（原式）----
function rt(p, phi) = [ p[0]*cos(phi) - (p[1]-BALL_Z)*sin(phi),
                        BALL_Z + p[0]*sin(phi) + (p[1]-BALL_Z)*cos(phi) ];
module profile(t) {
  phi = BANK * t;
  a = rt([ 6.5, BASE_Z+5], phi);
  b = rt([ 1.5, BASE_Z  ], phi);
  c = rt([-1.5, BASE_Z  ], phi);
  d = rt([-6.5, BASE_Z+5], phi);
  polygon([[-10,0], [10,0], [10,13], [a[0],13], a, b, c, d, [d[0],9], [-10,9]]);
}

// ---- 隧道座（v3：線圈有位、法蘭 D 槽定位）----
// 半座：只長「接縫本側」那一片，另一片由相鄰角件長 → 合起來剛好夾住 bobbin
module tun_add_half() {
  translate([DD-10, 14-CRADLE_T/2, 0]) cube([20, CRADLE_T, PLATE+13]);
}
module tun_cut_at() {
  translate([DD, 0, AXZ]) rotate([90,0,0]) cylinder(d=COIL_OD+0.8, h=26.4, center=true);
  translate([DD, 0, AXZ]) rotate([90,0,0]) cylinder(d=13.4, h=BOB_LEN+0.6, center=true);
  for (sf=[-1,1]) {
    translate([DD-9.12, sf*14-(CRADLE_T+0.7)/2, PLATE+Z_CUT]) cube([18.24, CRADLE_T+0.7, 20]);
    intersection() {
      translate([DD, sf*14, AXZ]) rotate([90,0,0])
        cylinder(d=FLANGE_D+0.6, h=CRADLE_T+0.7, center=true);
      translate([DD-15, sf*14-3, PLATE+Z_CUT]) cube([30, 6, 20]);
    }
  }
  translate([DD-11, -12, PLATE+6]) cube([22, 24, 12]);
}
// IR 光路：止於軌道外緣 ±10.5，不可打進夾座立柱
// （Ø3.5 孔底比 Ø3.2 槽底低 0.25，打穿的話元件落到孔底、光軸就偏了）
module ir_beam_hole(y) {
  translate([DD-10.5, y, PLATE+IR_Z]) rotate([0,90,0]) cylinder(d=IR_D, h=21);
}

// ---- 半段直線：y 0..30（0..15 為 t=0 線圈區，15..30 漸變）----
module half_straight() {
  translate([DD,0,0]) {
    translate([0,0,PLATE]) rotate([90,0,0]) {
      translate([0,0,-15]) linear_extrude(15.01) profile(0);
      for (i=[0:NSEG-1]) {
        t = i/(NSEG-1);
        translate([0,0,-(15+(i+1)*15/NSEG)]) linear_extrude(15/NSEG+0.02) profile(t);
      }
    }
    translate([-10,0,0]) cube([20, 30, PLATE]);           // 加厚底
  }
}
module corner90() {
  translate([C,C,0]) rotate_extrude(angle=90, $fn=240) {
    translate([R_C, PLATE]) profile(1);
    translate([R_C-10, 0]) square([20, PLATE+0.01]);      // 加厚底
  }
}

// ---- L 形角件：半直線 + 彎道 90° + 鏡射半直線 ----
// 接縫落在 (±115, 0) / (0, ±115) —— 也就是每個線圈隧道的正中央
// datum_gate：基準級多開一道測速孔（ERA：每級 1 道 + 基準級加 1 道 = 5 對）
module quarter(datum_gate=false) {
  difference() {
    union() {
      half_straight(); corner90(); mirror([1,-1,0]) half_straight();
      tun_add_half();  mirror([1,-1,0]) tun_add_half();
    }
    tun_cut_at(); mirror([1,-1,0]) tun_cut_at();
    ir_beam_hole(20);
    if (datum_gate) ir_beam_hole(27);
  }
}

// ---- 線圈組（bobbin + 繞線）----
module bobbin_coil() {
  translate([DD, 0, AXZ]) rotate([90,0,0]) {
    color("#8fc7e8") difference() {                       // bobbin
      union() {
        cylinder(d=BOB_OD, h=BOB_LEN, center=true);
        for (s=[-1,1]) translate([0,0,s*(BOB_LEN-FLANGE_T)/2])
          cylinder(d=FLANGE_D, h=FLANGE_T, center=true);
      }
      cylinder(d=BOB_ID, h=BOB_LEN+2, center=true);
      translate([-(FLANGE_D/2+1), -FL_FLAT-FLANGE_D, -BOB_LEN])   // D 截平
        cube([FLANGE_D+2, FLANGE_D, BOB_LEN*2]);
    }
    color("#b5651d") difference() {                       // 漆包線 Ø20.8×26
      cylinder(d=COIL_OD, h=BOB_LEN-2*FLANGE_T, center=true);
      cylinder(d=BOB_OD-0.1, h=BOB_LEN, center=true);
    }
  }
}

// ---- 場景 ----
QCOL = ["#c9ccd4", "#9aa7bd", "#b9c4b0", "#c6b8a8"];   // 4 角件異色：看得出分件與接縫位置
module track_all(ex=0) {
  for (i = [0:3]) rotate([0,0,i*90])
    translate([ex*0.7071, ex*0.7071, 0]) color(QCOL[i]) quarter(i==0);
}
module coils_all()  { for (i=[0:3]) rotate([0,0,i*90]) bobbin_coil(); }
module ball_on_curve() {
  rotate([0,0,45]) translate([C*sqrt(2)+R_C, 0, BZ])
    color("#e8e8ee") sphere(d=BALL_D);
}
module driver_board() {                                    // 集中驅動板（示意）
  translate([0,0,1.5]) {
    color("#1f6f43") cube([70,48,2.4], center=true);
    for (i=[-1.5:1:1.5]) color("#1a1a1a") translate([i*14, 16, 5]) cube([7,4.2,9], center=true);
    for (i=[-1.5:1:1.5]) color("#4a4a52") translate([i*14, -3, 9]) cylinder(d=13, h=15, center=true);
    color("#37474f") translate([0,-19,4]) cube([22,10,4], center=true);
  }
}
// IR 水平夾座（ERA 2026-07-31 核定：5 對對射、束高 z=11、光路水平橫穿）
// 元件躺槽底，槽心抬半個間隙 → 軸心正好落在束高（同隧道孔心的道理）
IR_BEAM = PLATE + IR_Z;          // 11
IR_SLOT = IR_BEAM + 0.1;         // 槽心 11.1（槽 Ø3.2 對元件 Ø3.0）
module ir_gate(y) {
  for (sf=[-1,1]) translate([DD + sf*13, y, 0]) {
    color("#b6bcc4") difference() {
      translate([-2.5, -3, 0]) cube([5, 6, 14]);
      translate([0,0,IR_SLOT]) rotate([0,90,0]) cylinder(d=3.2, h=9, center=true);
      translate([-4.5, -1.4, IR_SLOT]) cube([9, 2.8, 8]);            // 上開口，壓入卡住
    }
    translate([0,0,IR_BEAM]) rotate([0,90,0])
      color("#2b2b2b") cylinder(d=3, h=5, center=true);
  }
}
module ir_pairs() {
  for (i=[0:3]) rotate([0,0,i*90]) ir_gate(20);                      // 每級 1 道觸發
  ir_gate(27);                                                       // 基準級第 2 道（測速）
}

module scene_full() { track_all(); coils_all(); ball_on_curve(); ir_pairs(); driver_board(); }

if (view == "iso" || view == "top") scene_full();

// 這次要印的 4 個試配塊（直接讀出圖用的 STL，所見即所印）
if (view == "testfit") {
  color("#c9ccd4") import("test_v2_combo.stl");
  translate([60, 0, 0])   color("#9aa7bd") import("test_v2_joint_a.stl");
  translate([60, 45, 0])  color("#b9c4b0") import("test_v2_joint_b.stl");
  translate([100, 20, 0]) color("#8fc7e8") import("test_v2_bobbin.stl");
  translate([-45, 5, 0])  color("#c6b8a8") import("test_v2_ir.stl");
}

// 分解圖：4 角件沿對角外拉、線圈組垂直抬起（＝實際組裝動作：繞好線後垂直落入 D 槽）
if (view == "explode") {
  EX = 34;
  track_all(EX);
  for (i=[0:3]) rotate([0,0,i*90]) translate([EX*0.7071, EX*0.7071, 40]) bobbin_coil();
  driver_board();
}

// 單角件特寫：一個 L 件 + 它半邊的兩組線圈
if (view == "corner") {
  color("#c9ccd4") quarter();
  bobbin_coil();
  mirror([1,-1,0]) bobbin_coil();
  ball_on_curve();
}

// 透視圖：線圈／bobbin 半透明，看球在隧道內的位置與接縫落點
// （preview 模式下真剖切會被線圈斷面填滿，透明反而看得清楚）
if (view == "section") {
  intersection() {
    translate([DD-30, -46, -5]) cube([60, 92, 50]);         // 只留接縫段，好聚焦
    union() {
      color("#c9ccd4") quarter();
      color("#7d8aa0") rotate([0,0,-90]) quarter();         // 相鄰角件 → 接縫在 y=0 成形
      // 線圈組上半剖掉 → 直接看見球躺在 bobbin 內孔底（球心 z=11.218 恆定的來源）
      difference() {
        translate([DD, 0, AXZ]) rotate([90,0,0]) {
          color("#b5651d") difference() {                   // 漆包線
            cylinder(d=COIL_OD, h=BOB_LEN-2*FLANGE_T, center=true);
            cylinder(d=BOB_OD-0.1, h=BOB_LEN, center=true);
          }
          color("#8fc7e8") difference() {                   // bobbin
            union() {
              cylinder(d=BOB_OD, h=BOB_LEN, center=true);
              for (s=[-1,1]) translate([0,0,s*(BOB_LEN-FLANGE_T)/2])
                cylinder(d=FLANGE_D, h=FLANGE_T, center=true);
            }
            cylinder(d=BOB_ID, h=BOB_LEN+2, center=true);
            translate([-(FLANGE_D/2+1), -FL_FLAT-FLANGE_D, -BOB_LEN])
              cube([FLANGE_D+2, FLANGE_D, BOB_LEN*2]);
          }
        }
        translate([DD-20, -25, AXZ]) cube([40, 50, 25]);    // 剖掉上半
      }
      translate([DD, 0,  BZ]) color("#f2f4f8") sphere(d=BALL_D);   // 球在隧道正中＝接縫處
      translate([DD, 21, BZ]) color("#cfd6e0") sphere(d=BALL_D);   // 球在開放 V 槽
    }
  }
}

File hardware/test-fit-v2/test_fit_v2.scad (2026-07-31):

// ============================================================
// ERA v2 試配塊（Banked-Square 4 方案；派工 2026-07-28）
// 剖面函式移植自 era_concept_v2.scad（profile/rt 原式）
//
// 重要修正（回報 ERA 核定）：隧道孔心高不能等於球心 8.218——
//   球在 Ø11.2 孔內躺孔底滾，孔心 8.218 → 球心跌 0.85。
//   本檔採 BORE_Z = BALL_Z + (孔徑-球徑)/2 = 9.068，
//   孔底 3.468 = V 槽滾動面 → 全程球心 8.218 恆定（真零落差）。
// 另：法蘭 Ø22 低於軌道底板基準 1.93mm → 試配塊底板局部加厚 3
//   （正式件需同樣處理：局部加厚或開法蘭沉槽）
// ============================================================
part = "combo"; // combo | bobbin | joint_a | joint_b | ir

$fn = 128;

BALL_D  = 9.5;
BASE_Z  = 3;
BALL_Z  = BASE_Z + 5.218;      // 8.218
BANK    = 20;
R_C     = 85;
BOB_ID  = 11.2; BOB_WALL = 0.8; BOB_OD = BOB_ID+2*BOB_WALL;  // 12.8
BOB_LEN = 30; FLANGE_D = 22; FLANGE_T = 2;
BORE_Z  = BALL_Z + (BOB_ID-BALL_D)/2;   // 9.068（見上）
IR_D    = 3.5; IR_Z = 8;
Z_CUT   = 2.5;   // D形法蘭截平面的絕對高（基準3-0.5）。繞線鬆脫備案：改1.5
                 // （無擋線角 94.2°→80.8°、隧道底膜 5.2→4.2；下限≈0.12）
FL_FLAT = BORE_Z - Z_CUT;   // 截平距 bobbin 軸心 6.568

NSEG = 30;   // 漸變段 15mm 分 30 片（0.5mm/片，比概念圖細一倍）

// ---- 原式移植 ----
function rt(p, phi) = [ p[0]*cos(phi) - (p[1]-BALL_Z)*sin(phi),
                        BALL_Z + p[0]*sin(phi) + (p[1]-BALL_Z)*cos(phi) ];
module profile(t) {
  phi = BANK * t;
  a = rt([ 6.5, BASE_Z+5], phi);
  b = rt([ 1.5, BASE_Z  ], phi);
  c = rt([-1.5, BASE_Z  ], phi);
  d = rt([-6.5, BASE_Z+5], phi);
  polygon([[-10,0], [10,0], [10,13], [a[0],13], a, b, c, d, [d[0],9], [-10,9]]);
}

// ============================================================
// (1) 彎道試配：直線 40（含漸變 15）＋ R85 弧 45°
//     直線沿 +y；y25..40 漸變 t 0→1；彎道左轉（中心 (-85,40)）
// ============================================================
module curve_test() {
    // 直線段 t=0（y 0..25）
    rotate([90,0,0]) translate([0,0,-25]) linear_extrude(25.01) profile(0);
    // 漸變段（y 25..40）
    for (i=[0:NSEG-1]) {
        t = i/(NSEG-1);
        rotate([90,0,0]) translate([0,0,-(25+(i+1)*15/NSEG)])
            linear_extrude(15/NSEG+0.02) profile(t);
    }
    // 彎道 45° t=1
    translate([-R_C, 40, 0]) rotate_extrude(angle=45, $fn=400)
        translate([R_C, 0]) profile(1);
}

// ============================================================
// (2) bobbin 薄壁樣（立印）
// ============================================================
module bobbin() {
    difference() {
        union() {
            cylinder(d=BOB_OD, h=BOB_LEN);
            for (z=[0, BOB_LEN-FLANGE_T]) translate([0,0,z]) cylinder(d=FLANGE_D, h=FLANGE_T);
        }
        translate([0,0,-1]) cylinder(d=BOB_ID, h=BOB_LEN+2);
        // 出線孔（兩法蘭）
        for (z=[FLANGE_T/2, BOB_LEN-FLANGE_T/2])
            translate([BOB_OD/2+2.5, 0, z]) cylinder(d=1.6, h=FLANGE_T+2, center=true);
        // D 形法蘭：下緣截平於軸心下 FL_FLAT（膜厚問題根治；擋線靠張力非法蘭——ERA 核定）
        translate([-(FLANGE_D/2+1), -FL_FLAT-FLANGE_D, -1]) cube([FLANGE_D+2, FLANGE_D, BOB_LEN+2]);
    }
}

// ============================================================
// (3) 隧道段試配：直線軌 74 + 中央 bobbin 巢座 + IR 孔
//     底板整體 +3 加厚（法蘭 Ø22 需沉入基準面下 1.93）
//     驗證：球 V 槽 → 隧道孔底 → V 槽全程球心同高
// ============================================================
module tunnel_test() {
    difference() {
        union() {
            // 加厚底 3 + 軌道剖面（整體抬 3）
            translate([-10, -37, 0]) cube([20, 74, 3]);
            translate([0,0,3]) rotate([90,0,0]) translate([0,0,-37]) linear_extrude(74) profile(0);
            // bobbin 巢座肋 ×2（在法蘭內側 ±11，U 巢 Ø12.9）
            for (sy=[-11,11-4]) translate([-10, sy, 0]) cube([20, 4, 3+BORE_Z]);
        }
        // 隧道包絡：Ø13.4 沿 y 貫通中央 38（含法蘭 34 +餘裕）
        translate([0, 0, 3+BORE_Z]) rotate([90,0,0]) cylinder(d=13.4, h=38, center=true);
        // 巢座肋開 U 巢（Ø12.9 貼管）
        for (sy=[-11.5, 11.5]) translate([0, sy, 3+BORE_Z])
            rotate([90,0,0]) cylinder(d=BOB_OD+0.3, h=5, center=true);
        // 法蘭淺沉槽（槽底 = Z_CUT-0.3 餘裕；Z_CUT=2.5 時底膜 5.2、1.5 時 4.2）
        for (sy=[-15+FLANGE_T/2+0.1, 15-FLANGE_T/2-0.1]) translate([-12, sy-(FLANGE_T+0.7)/2, 3+Z_CUT-0.3])
            cube([24, FLANGE_T+0.7, 14]);
        // 兩側牆在隧道區開窗（放線圈外徑 ~20.8）
        translate([-11, -12, 3+6]) cube([22, 24, 12]);
        // IR：牆上 Ø3.5 橫向對穿（z = 3+IR_Z）＋外側 x±13 直立管座
        translate([-16, -22, 3+IR_Z]) rotate([0,90,0]) cylinder(d=IR_D, h=32);
        for (sx=[-13,13]) translate([sx, -22, -1]) cylinder(d=IR_D, h=3+IR_Z+1+1.75);
    }
    // IR 管座外擴底板
    difference() {
        translate([-16, -26, 0]) cube([32, 8, 3]);
        for (sx=[-13,13]) translate([sx, -22, -1]) cylinder(d=IR_D, h=6);
        translate([-16, -26, 0]) cube([0,0,0]);
    }
}

if (part=="curve")  curve_test();
if (part=="bobbin") bobbin();
if (part=="tunnel") tunnel_test();


// ============================================================
// (合併版) combo：彎道45°→漸變15→直線60（含隧道巢座+IR）一體件
// 基準統一：底板全周 6（=正式件定案），球心 11.218、孔心 12.068
// 理由（ERA 建議核定）：正式件一體無接縫，「過渡零落差」不能用
// 拼接驗——接縫誤差會污染核心驗證項。bobbin 維持獨立（繞線後裝）。
// ============================================================
module combo_test() {
    difference() {
        union() {
            // 加厚底（直線+漸變）
            translate([-10, 0, 0]) cube([20, 75, 3]);
            // 直線 t=0（y 0..60）
            translate([0,0,3]) rotate([90,0,0]) translate([0,0,-60]) linear_extrude(60.01) profile(0);
            // 漸變 y60..75
            for (i=[0:NSEG-1]) {
                t = i/(NSEG-1);
                translate([0,0,3]) rotate([90,0,0]) translate([0,0,-(60+(i+1)*15/NSEG)])
                    linear_extrude(15/NSEG+0.02) profile(t);
            }
            // 彎道 45°（含自己的加厚底）
            translate([-R_C, 75, 0]) rotate_extrude(angle=45, $fn=400) union() {
                translate([R_C, 3]) profile(1);
                translate([R_C-10, 0]) square([20, 3.01]);
            }
            // 隧道座（v3 共用：法蘭 D 槽定位）
            tun_add(30);
            // IR 管座翼板（y 6..14）
            translate([-16, 6, 0]) cube([32, 8, 3]);
        }
        tun_cut(30);
        // IR：牆上 Ø3.5 橫穿（y=10, z=基準6+5=11）＋ x±13 直立管座
        translate([-16, 10, 3+IR_Z]) rotate([0,90,0]) cylinder(d=IR_D, h=32);
        for (sx=[-13,13]) translate([sx, 10, -1]) cylinder(d=IR_D, h=3+IR_Z+2.75);
    }
}
if (part=="combo") combo_test();


// ============================================================
// 接縫試配對（David 需求 2026-07-31：軌道分件卡榫）
// 概念：正式件切 4 個 L 形角件，接縫全部落在「線圈隧道正中央」——
// 球在隧道內騎 bobbin 內孔（單一件），全程摸不到軌道接縫。
// 接合 = 底部燕尾搭接舌（z0..3、план燕尾、垂直落入）＋bobbin 本身兼對位銷。
// joint_a + joint_b 組起來 = 一段帶接縫的隧道直線段，供實測驗證。
// ============================================================
DT_NECK=10; DT_HEAD=16; DT_LEN=9; DT_CL=0.4;   // 燕尾（FDM 鐵律間隙）

// ---- 隧道座共用（v3：線圈 Ø20.8 有位、法蘭 D 槽定位，繞線區零遮擋）----
CRADLE_T = 2.7; COIL_OD = 20.8;
module tun_add(yc) {   // 法蘭座板 ×2（@ yc±14）
    for (sf=[-1,1]) translate([-10, yc+sf*14-CRADLE_T/2, 0]) cube([20, CRADLE_T, 13]);
}
module tun_cut(yc) {
    // 線圈包絡：長度須蓋滿繞線區 26（+0.2/端），否則線圈端撞座板（法蘭讓位已不再兼差挖這裡）
    translate([0, yc, 3+BORE_Z]) rotate([90,0,0]) cylinder(d=COIL_OD+0.8, h=26.4, center=true);
    // 光管讓位：長度＝bobbin 光管 30 +0.3/端。**切勿放長**——多切一段就是一段
    // 「V 槽沒了、bore 還沒開始」的無支撐區，球會在隧道進出口跌落
    // （實測：舊值 h=38 兩端各留 4mm 空檔 → 球心掉到 10.776，−0.44mm）
    translate([0, yc, 3+BORE_Z]) rotate([90,0,0]) cylinder(d=13.4, h=BOB_LEN+0.6, center=true);
    // 法蘭 D 座槽：垂直落入通道（弦寬+0.3/側）＋圓弧讓位；D 平面落 z5.5 = 基準
    for (sf=[-1,1]) {
        translate([-9.12, yc+sf*14-(CRADLE_T+0.7)/2, 3+Z_CUT]) cube([18.24, CRADLE_T+0.7, 20]);
        // 圓弧讓位只切基準面以上：法蘭 D 面就落在 z=3+Z_CUT，底下不必讓
        // （切成整圓會把座板根部底膜啃到 0.75mm——上次回報 ERA 的 5.2mm 是錯的）
        intersection() {
            translate([0, yc+sf*14, 3+BORE_Z]) rotate([90,0,0])
                cylinder(d=FLANGE_D+0.6, h=CRADLE_T+0.7, center=true);
            translate([-15, yc+sf*14-3, 3+Z_CUT]) cube([30, 6, 20]);
        }
    }
    translate([-11, yc-12, 3+6]) cube([22, 24, 12]);                                          // 側牆開窗
}


module joint_straight() {   // 完整 60 直線含隧道特徵（接縫將落 y=30）
    difference() {
        union() {
            translate([-10, 0, 0]) cube([20, 60, 3]);
            translate([0,0,3]) rotate([90,0,0]) translate([0,0,-60]) linear_extrude(60.01) profile(0);
            tun_add(30);
        }
        tun_cut(30);
    }
}
module dovetail_plan(cl=0) {   // 平面燕尾（+y 指向）
    polygon([[-DT_NECK/2-cl, -1],[DT_NECK/2+cl, -1],
             [DT_NECK/2+cl, 0.01],[DT_HEAD/2+cl, DT_LEN+cl],
             [-DT_HEAD/2-cl, DT_LEN+cl],[-DT_NECK/2-cl, 0.01]]);
}
module joint_a() {   // y 0..30 ＋ 底部燕尾舌（伸入 B；舌需同受線圈包絡刀）
    difference() {
        union() {
            intersection() { joint_straight(); translate([-11,-1,-1]) cube([22, 31, 30]); }
            translate([0, 30, 0]) linear_extrude(3) dovetail_plan(0);
        }
        tun_cut(30);
    }
}
module joint_b() {   // y 30..60 － 底部燕尾槽
    difference() {
        intersection() { joint_straight(); translate([-11, 30, -1]) cube([22, 31, 30]); }
        translate([0, 30, -1]) linear_extrude(5) dovetail_plan(DT_CL);
    }
}
if (part=="joint_a") joint_a();
if (part=="joint_b") joint_b();
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

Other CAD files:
hardware/concept/era_concept_v1.scad
hardware/test-fit/test_fit.scad

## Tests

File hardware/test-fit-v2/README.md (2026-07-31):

# v2 試配塊（方案 B / Banked-Square 4）

對應設計文件：[docs/design-v2-alt.md](../../docs/design-v2-alt.md)　由 `stl` session 出圖。
原始參數化檔：`test_fit_v2.scad`。

## 印這些

**主件（必印）**

| 檔案 | 尺寸 / 擺法 | 驗什麼 |
|---|---|---|
| `test_v2_combo.stl` | 48×142×16，**平躺** | 一體連續軌道：彎道弧 45° → 漸變 15 → 直線段 60（含隧道巢座 + 法蘭淺槽 + IR 孔）。驗滾動順暢度、**banking 過渡有無頓挫**、進出隧道零落差、IR 對光 |
| `test_v2_bobbin.stl` | 22×17.6×30（D 形法蘭），**立印** | 0.8mm 薄壁列印品質、Ø9.5 球通過性、繞線手感 |

**分件架構評估（可選，決定正式件要不要分 4 件時才需要）**

| 檔案 | 尺寸 / 擺法 | 驗什麼 |
|---|---|---|
| `test_v2_joint_a.stl` / `test_v2_joint_b.stl` | 各 20×(30~39)×16，平躺 | 「縫藏隧道」接合對：**繞好線的 bobbin 裝上後，球通過接縫在隧道內是否無感** |
| `test_v2_ir.stl` | 32×20×16，平躺 | IR 水平夾座：**3mm 對射管從上方壓入是否卡得住**、光軸對準、球放上去實際遮斷 |

列印設定：PETG、0.2 層高。bobbin 用 **2 週線、關填充**（薄壁件），其餘照常。

> **v3 隧道座修正（David 抓到的真 bug）**：舊版隧道座只留了光管 Ø13.4 的包絡，
> **繞好線的線圈 Ø20.8 根本放不進去**，中段巢肋還壓在繞線區上。
> 已改為線圈包絡 Ø21.6、巢座改法蘭 D 槽（D 平面落在 z=5.5 做精確 xz 定位、Ø22.6 圓弧讓位、
> 繞線區 26.4mm 零遮擋）。
>
> **v3.1 沿路徑掃描複檢**（stl 改用沿路徑掃描重驗，抓到兩個逐截面驗證看不見的 bug）：
> ①隧道進出口球心下沉——光管讓位孔開 h=38 但 bobbin 只有 30，兩端各 4mm 是「V 槽已挖掉、
> 內孔還沒開始」的無支撐段，球心掉到 10.776（−0.442）。改 h=30.6，V 槽一路頂到孔口，沉降 <0.02。
> ②法蘭座根部底膜只剩 0.75——法蘭圓弧讓位 Ø22.6 切成整圓，把基準面以下也啃掉了；
> 法蘭 D 面本來就在 z=5.5，底下不必讓 → 讓位限制在 z≥5.5，底膜回到 5.35。
> 另彎道 `rotate_extrude` $fn 200→400（多邊形化假影 +0.023→+0.005，非設計誤差）。
>
> 複檢後全數據：**球心全程落差 0.006mm**（424 取樣點，涵蓋直線／隧道／漸變／彎道／接縫段）；
> bobbin 入座、線圈 Ø20.8×26、joint A×B 干涉皆 0.000；bobbin 由上方垂直落入的組裝路徑（25 個高度）亦 0 干涉。

> 為什麼是一體的 combo 而不是分開的軌道段＋隧道段：正式件本來就是一體列印無接縫，
> 用拼接來驗證過渡會引入正式件根本不存在的接縫誤差——而「過渡零落差」正是 v2 最核心的
> 驗證項，不該用會污染結果的方式去驗。（初版曾出分離的 curve + tunnel，已作廢移除。）

## 關鍵幾何（基準統一，CAD 驗證干涉 0.000）

- 球 Ø9.5，**球心高 11.218**（底板 6 + 5.218）
- 底面單一平面 z=0，底板全周 6mm，槽底基準面 z=6
- 直線段：對稱 45° V 槽，平底寬 3
- 彎道：整個槽輪廓繞球心旋轉 **20°**（外側面 65°、內側面 25°，槽夾角維持 90°），R=85
- 漸變段 15mm（30 片近似），只有 banking 角 0°→20° 線性變化，**球心高度全程不變**
- 隧道**孔心 12.068** = 球心 11.218 + 間隙/2 0.85（球躺孔底滾，孔心與球心不同高）
- D 形法蘭截平面 z=5.5（基準面下 0.5），沉槽底 5.2，**底膜 5.20mm**
- 球心 11.218 在彎道 / 漸變段 / 直線段三處皆恰相切

量測驗證（收錄時實測 STL 頂點）：關鍵 z 平面 0 / 5.200 / 5.802 / 6.000 / 6.828 / 8.790 / 11.000 / 12.000 / 13.236 / 16.000，
與設計值逐項對上；bobbin 截平距軸心 6.568，配孔心 12.068 得截平面 5.5 ✓ 兩件一致。

## 繞線提醒

法蘭半徑 11 只比線圈外徑（20.8）大 0.6mm/邊，對 0.5mm 線僅夠擋一層多；
D 形截平後正下方約 94° 沒有側擋。**繞線全程保持張力，繞完立刻用膠帶／熱縮套固定端頭**，不要指望法蘭擋線。
若線容易鬆脫，`test_fit_v2.scad` 的 `Z_CUT` 從 2.5 下修到 1.5 重出（無擋線角 94.2°→80.8°，底膜 5.2→4.2 仍充裕）。

## 試印時要看什麼

1. 球放上去手推，**過渡段有沒有頓一下**——這是 v2 最核心的假設（banking 漸變不改變球心高度）
2. 彎道裡快速推球，看球是**貼在 65° 面上滾**還是爬到外牆上
3. bobbin 0.8 壁有沒有破洞、Ø9.5 球通過是否順暢
4. IR Ø3.5 孔試插 3mm 對射管，兩側對光是否通
5. 球從開放槽進 bobbin 內孔，**有沒有可感的落差或撞擊聲**
6. **繞好線的 bobbin 真的裝得進巢座嗎**（v3 修正的就是這件事，務必用繞完線的實物試，不要用光管試）
7. （若印了 joint 對）A/B 接起來裝上 bobbin，**球通過接縫在隧道內是否無感**
8. （IR 試片）3mm 對射管從上方壓入 U 槽——槽口收窄到 2.8 靠彈性卡住，
   **壓得進去嗎、卡得住嗎**（走壓潰/卡入路線，不賭尺寸公差），以及球放上去是否真的遮斷光路

順帶留意一處：**繞線區正中的底部只有 1.268mm 材料**（實測），而且這是幾何必然、改不掉的——
線圈 Ø20.8 的最低點落在 z=1.668，比法蘭 D 面（z=5.5）還低 3.83mm，抬不起來。
該區的剛性要算**兩側側牆**而不是底膜。手扳看看該處，若太軟要回報——分件版的 4 個接縫都落在這裡。

結果回報後，stl 才出正式件。

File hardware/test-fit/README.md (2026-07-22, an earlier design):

# em-accelerator — 電磁環形加速器（試配塊階段）

規格（ERA session 派工 2026-07-22）：鋼球 Ø12.7、中心圓 Ø240 一體印、4 線圈段、
bobbin ID14.5/壁0.8/C形/法蘭Ø26、IR Ø3 對射孔、PETG。

## 試配塊（先印這盤）

| 檔案 | 驗什麼 |
|---|---|
| `test_bobbin.stl`（26×26×24，立印） | 0.8 薄壁列印品質、球通過性、C 縫、法蘭出線孔、漆包線繞線手感 |
| `test_track.stl`（23×67×17 弧段，平躺） | 45° 雙軌滾動手感（球心 9.98 相切已 CAD 驗證）、外牆高度、IR Ø3 孔穿線與對光 |

## 已定的幾何核心（正式件沿用）

- U 槽剖面：底板 3、平底 4、45° 斜軌到 z8、內牆 z10、外牆 z17（高過球心抗離心）
- 球心高：開放段騎雙軌 = **9.98**；隧道段騎 bobbin 孔底 → **孔心 10.88** 時球心同高，
  過渡零落差（正式件的軌道↔bobbin 接合按此對位）
- IR 束高 z9（略低於球心，遮斷可靠）

試印重點：bobbin 用 0.2 層高、2 週線、關填充；track 弧段照常。
球放軌上手推應順滑無稜感；IR 孔試插 3mm 對射管。

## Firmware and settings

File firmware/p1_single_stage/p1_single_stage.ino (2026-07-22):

// P1 單級直線驗證韌體 — XIAO ESP32-S3
// 時序：IR 閘門1 觸發 → 延遲 d → 線圈脈衝寬 w → 關斷
// 閘門1/閘門2 間距 GATE_SPACING_MM 測球速；序列埠即時調參
//
// 接線（見 my_car emring-driver.html 與 coil-and-driver-spec.md）：
//   IR 前端【定案】：光電晶體「集極輸出」——集極接 GPIO（內部上拉 INPUT_PULLUP）、
//   射極接 GND。受光導通=LOW、遮光截止=HIGH → 觸發邊緣 RISING、卡球判 HIGH（三處一致）
//   GPIO1 = IR 閘門1、GPIO2 = IR 閘門2（測速用，可先不接）
//   GPIO4 (D3) = MOSFET 閘極（→100Ω→IRLB8721 G）。板上 10k 閘極下拉必須保留：
//   開機/燒錄瞬間 GPIO 為 hi-Z，全靠它防線圈誤導通；並刻意避開 strapping 腳 GPIO3
// 序列埠指令：d <us> 設延遲 / w <us> 設脈寬 / s 顯示參數 / e 0|1 停用/啟用

const int PIN_GATE1 = 1;
const int PIN_GATE2 = 2;
const int PIN_COIL  = 4;

// my_car 脈寬對球速表（w≈d_eff/v，d_eff≈10mm，實務再提早~1ms 關斷防 suck-back）：
//   0.5m/s→19ms  1.0→9ms  1.5→5.7ms  2.0→4.0ms  2.5→3.0ms  3.0→2.3ms
// 0.5–3m/s 全在電流飽和區（τ≈0.65ms），調校重點只在「關斷時機」。
const float GATE_SPACING_MM = 30.0;   // 閘門1→閘門2 間距，依實裝修改
const uint32_t PULSE_MAX_US = 25000;  // 安全上限 25ms（涵蓋 0.5m/s 慢速；單發熱 ~1.8J 仍安全）
const uint32_t REARM_MIN_US = 30000;  // 兩次觸發最小間隔，防抖/防連發
const uint32_t STUCK_MS     = 500;    // 閘門遮擋超過此值視為卡球/故障 → 停用

uint32_t delay_us = 0;      // d：觸發後延遲
uint32_t pulse_us = 10000;  // w：起手 10ms（對應手推入球 ~1m/s，實測後調）
bool enabled = true;

volatile uint32_t t_gate1 = 0, t_gate2 = 0;
volatile bool fired = false;

void IRAM_ATTR onGate1() { t_gate1 = micros(); fired = true; }
void IRAM_ATTR onGate2() { t_gate2 = micros(); }

void setup() {
  pinMode(PIN_COIL, OUTPUT);
  digitalWrite(PIN_COIL, LOW);
  pinMode(PIN_GATE1, INPUT_PULLUP);
  pinMode(PIN_GATE2, INPUT_PULLUP);
  attachInterrupt(digitalPinToInterrupt(PIN_GATE1), onGate1, RISING);
  attachInterrupt(digitalPinToInterrupt(PIN_GATE2), onGate2, RISING);
  Serial.begin(115200);
  Serial.println("P1 single stage ready. cmds: d <us> | w <us> | s | e 0|1");
}

void firePulse() {
  // d 以 t_gate1 中斷瞬間為基準，扣掉 loop 服務延遲（防時序抖動）
  uint32_t elapsed = micros() - t_gate1;
  if (delay_us > elapsed) delayMicroseconds(delay_us - elapsed);
  digitalWrite(PIN_COIL, HIGH);
  // 脈寬用 micros() 截止時間：delayMicroseconds 傳大值不保證準
  uint32_t t_off = micros() + min(pulse_us, PULSE_MAX_US);
  while ((int32_t)(t_off - micros()) > 0) {}
  digitalWrite(PIN_COIL, LOW);
}

void loop() {
  static uint32_t last_fire = 0;

  if (fired) {
    fired = false;
    uint32_t now = micros();
    if (enabled && (now - last_fire) > REARM_MIN_US) {
      last_fire = now;
      firePulse();
      Serial.printf("fired: d=%luus w=%luus\n", delay_us, pulse_us);
    }
  }

  // 測速：閘門2 晚於閘門1 → v = s/Δt
  static uint32_t last_report = 0;
  if (t_gate2 > t_gate1 && t_gate1 && t_gate2 != last_report) {
    last_report = t_gate2;
    float dt_s = (t_gate2 - t_gate1) / 1e6;
    Serial.printf("speed: %.2f m/s (dt=%luus)\n",
                  GATE_SPACING_MM / 1000.0 / dt_s, t_gate2 - t_gate1);
  }

  // 安全：閘門1 持續遮擋或斷線（皆讀 HIGH）→ 停用並確保線圈關斷
  static uint32_t blocked_since = 0;
  if (digitalRead(PIN_GATE1) == HIGH) {
    if (!blocked_since) blocked_since = millis();
    else if (millis() - blocked_since > STUCK_MS && enabled) {
      enabled = false;
      digitalWrite(PIN_COIL, LOW);
      Serial.println("!! gate1 stuck blocked -> disabled (e 1 to re-arm)");
    }
  } else blocked_since = 0;

  // 序列埠調參
  if (Serial.available()) {
    String line = Serial.readStringUntil('\n');
    char cmd = line.charAt(0);
    long v = line.substring(1).toInt();
    if (cmd == 'd') { delay_us = v; }
    else if (cmd == 'w') { pulse_us = min((uint32_t)v, PULSE_MAX_US); }
    else if (cmd == 'e') { enabled = v; if (!v) digitalWrite(PIN_COIL, LOW); }
    Serial.printf("d=%luus w=%luus enabled=%d\n", delay_us, pulse_us, enabled);
  }
}

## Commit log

2026-07-22 Day 1: 原理研究、方案定案、電路規格、P1 韌體與試配塊派工
    - RESEARCH/PLAN：磁阻式線圈砲環形版方案 v0.1（Ø240 一體環軌、4 線圈段）
    - coil-and-driver-spec：線圈估算與驅動電路（my_car session 交付）
    - firmware/p1_single_stage：單級驗證韌體（IR 觸發、測速、三道安全保護）
    - docs/log：Day 1 開發日誌（部落格素材）
2026-07-22 hardware/test-fit: 收錄 stl session 出圖的試配塊（STL+SCAD）
    [test_bobbin.stl, test_fit.scad, test_track.stl]
2026-07-23 concept v1：3D 概念示意圖（OpenSCAD 模型 + 三視角渲染，README 嵌圖）
    [era_concept_v1.scad]
2026-07-23 採購清單：工具類（烙鐵/焊錫/三用電表/USB-C）確認已有，併入既有免購
2026-07-23 採購清單：明列電阻包需求（100Ω×12、10k×4、指示LED 220Ω-1k×4 選配）
2026-07-28 方案 B（v2）：獨立重新推導的替代設計 + v1 對照
    不參考 v1 結論從物理重推，得到五個 v1 未涵蓋的量化結果：
    1. 閉合軌道側向摩擦 W = 2π·μ·m·v²，與半徑及形狀無關
    → 只能靠 banking（降 μ）與小球（降 m）改善
    2. v1 對稱 45° V 槽在 1.08 m/s 就讓球爬上外牆，
    接觸由滾動轉滑動、摩擦跳 7 倍
    → 彎道 banking 20°（外 65°/內 25°）把上限拉到 1.34 m/s
    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
    [era_concept_v2.scad]
2026-07-28 核定 stl 兩項修正：v2 隧道孔心 9.068、v1 概念圖剖面補回 45°
    (1) v2 隧道孔心 = 球心 + 間隙/2，不是 = 球心
    球在 bobbin 內孔是躺在孔底滾，不是懸在孔軸上：
    球心 = 孔心 − (11.2 − 9.5)/2 = 孔心 − 0.85
    → 孔心 9.068 才能讓球心維持 8.218
    原派工單寫「孔心 = 球心 8.218」會讓球進隧道時跌 0.85mm，
    正好發生在加速段。v1 早就處理對了（9.98/10.88 差 0.90），
    是 v2 沿用時把這個關係弄丟。stl 出圖時抓出。
    連帶：法蘭 Ø22 下緣落在 −1.93，底板需沉槽或局部加厚。
    (2) era_concept_v1.scad 的 35.5° 根因＝外側漏了斜面頂點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
    [era_concept_v1.scad, era_concept_v2.scad]
2026-07-28 hardware/test-fit-v2: 收錄 stl 出圖的 v2 三件試配塊
    test_v2_curve（直線40+漸變15+R85弧45°，驗 banking 過渡）
    test_v2_bobbin（Ø22×30 立印，驗 0.8 壁與 Ø9.5 球通過）
    test_v2_tunnel（含 bobbin 巢座/法蘭沉槽/IR 孔，驗零落差）
    含 test_fit_v2.scad 參數化原始檔與試印重點 README。
    CAD 驗證：球心 8.218 於直線/漸變中點/彎道 22.5° 三處恰相切
    （干涉 0.000）、bobbin 入巢 0 干涉、球經隧道球心恆高。
    [test_fit_v2.scad, test_v2_bobbin.stl, test_v2_curve.stl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]
2026-07-28 法蘭座定案（stl）：線圈區局部加厚 +3，法蘭槽開在加厚墊內
    3mm 底板直接開 1.93+餘裕的沉槽後只剩約 0.7mm 膜，懸空區易翹
    易破；加厚墊可全實心列印，並順帶給集中驅動板提供鎖點。
2026-07-28 底板定案（stl）：全周 3→6，底面整體下移，幾何不動
    側面加肉解不了（法蘭要的是基準面下方的空間）；只加厚線圈區
    則底面不平、253mm 一體大件貼床會翹。全周下移可維持底面同一
    平面、貼床面積不減，法蘭槽開在 6mm 厚度裡。
    代價約 +58g，換整圈剛性提升與零翹曲風險。球心 8.218 / 孔心
    9.068 等幾何全部不變。
    概念 SCAD 導入 PLATE_BOT=-3，驅動板組件一併坐到新底座高度。
    [era_concept_v2.scad]
2026-07-28 D 形法蘭定案（stl）：釜底抽薪解決底膜厚度
    底板加到 6mm 後膜厚仍只有 0.77mm——根源是法蘭半徑 11 大於
    孔心到基準面的距離 6.068，圓法蘭必然伸進基準面下 4.93mm，
    底板加多厚都只是把它往下推。
    解法改為削掉法蘭用不到的部分：下緣截平於基準面下 0.5，
    弦半寬 √(11²−6.568²)=8.82 → 外形 22×17.6，沉槽只需淺槽，
    底膜回到 5.20mm。立印姿態不變。
    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
    [era_concept_v2.scad, test_fit_v2.scad, test_v2_bobbin.stl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]
2026-07-28 同步 stl 參數化版：Z_CUT 可調（2.5 現行 / 1.5 鬆線備案）
    STL 幾何本輪不變，僅把 D 形法蘭截平高度提為參數：
    Z_CUT = 2.5 → 無擋線角 94.2°、底膜 5.2mm（現行）
    Z_CUT = 1.5 → 無擋線角 80.8°、底膜 4.2mm（繞線鬆脫時改用）
    Z_CUT ≤ 0.12 → 弦半寬小於筒身半徑，法蘭切進筒身，不可用
    [test_fit_v2.scad, test_v2_bobbin.stl, test_v2_tunnel.stl]
2026-07-28 開發日誌 Day 2：重新設計一次，四個來回抓出五個錯
    記錄 v2 獨立重推的五個發現，以及派工後與 stl 之間四輪互相
    審查的完整過程（誰抓到誰、每個錯的根因與最終解）。
    三個關於做設計的心得：
    - 獨立重推的價值不在推出不同答案，在推出同樣答案的不同理由
    - 最危險的不是算錯的地方，是沒算的地方（孔心錯在「沿用」而非「重推」）
    - 「錯的方向」比「錯的數值」更值得注意——兩個錯都朝最不利那邊
2026-07-30 試配塊改一體 combo：修正基準不同步，並讓過渡可驗
    David 試組發現高度不對且三件無法接合。量測確認兩個問題：
    1. test_v2_curve 是「底板全周 3→6」定案前的版本，沒跟著重出：
    curve Z 0..13，平底 3.000 → 球心 8.218
    tunnel Z 0..16，平底 6.000 → 球心 11.218
    同批件基準差正好 3.000mm。（bobbin 與 tunnel 本身一致。）
    2. 三件座標系不同、無榫接特徵，拼不成連續軌道——而過渡零落差
    正是 v2 最核心的驗證項，接不起來就驗不到。
    改為一體 test_v2_combo（48×142×16）：彎道弧 45° → 漸變 15 →
    直線 60（含隧道巢座+法蘭淺槽+IR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
    [test_fit_v2.scad, test_v2_combo.stl, test_v2_curve.stl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]
2026-07-31 v3.1 隧道座與分件架構：收錄複檢修正、預覽圖、縫藏隧道方案
    隧道座 v3（David 抓到的真 bug）：舊版只留光管 Ø13.4 包絡，
    繞好線的線圈 Ø20.8 放不進、中段巢肋壓在繞線區上。改為線圈
    包絡 Ø21.6、巢座改法蘭 D 槽，繞線區 26.4mm 零遮擋。
    v3.1 沿路徑掃描複檢，抓到兩個逐截面驗證看不見的 bug：
    ①隧道進出口 4mm 無支撐段使球心下沉 0.442 → h 改 30.6，沉降 <0.02
    ②法蘭讓位切成整圓啃到基準面以下，底膜 0.75 → 限制 z≥5.5，回到 5.35
    複檢後球心全程落差 0.006mm（424 取樣點）。
    入庫實測驗證（對稱條款）：新增 z=5.500 平面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
    [preview_v2.scad, test_fit_v2.scad, test_v2_combo.stl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]
2026-07-31 IR 水平夾座 + 半個間隙通則
    夾座照核定規格：5 對對射、光路水平橫穿、束高 z=11。元件 Ø3.0
    從上方壓入水平 U 槽，槽口收窄 2.8 靠彈性卡住（走壓潰/卡入路線，
    不賭尺寸公差）。ir_clip() 正式件可直接沿用。
    stl 於設計時撞到同一個關係的第三次重複，並自己踩到一個新 bug：
    光路孔 Ø3.5 打穿立柱，比定位槽 Ø3.2 大、孔底 9.25 低於槽底 9.5，
    元件會滑進去落到孔底、光軸偏低 0.25。修法是光路孔止於軌道外緣
    ±10.5 不進立柱。入庫實測確認孔底頂點只到 |x|=10.500 ✓
    歸納成通則寫進設計文件：孔心 = 物體軸心 + (孔徑−物體徑)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
    [preview_v2.scad, test_fit_v2.scad, test_v2_ir.stl]
2026-08-03 採購清單：蝦皮實查三樣試配耗材，已加入購物車待結帳
    鋼珠 9.52mm(3/8") 50只 $100（鼎興科技五金，碳鋼、台灣製 ROHS、
    8/5-8/6 到）；漆包線 #25/0.5mm 100g ×2 $330（8/5-8/6）；
    祥昌電子 3mm 940nm 發射器 ×8 + 光敏接收器 ×8 $48（8/5-8/7）。
    兩項實查得到的技術確認：
    - 市售標準是 9.52mm(3/8") 而非 9.5mm，大 0.025mm → 球心高度差
    <0.02mm、孔心差 0.0125mm 皆可忽略，直接用；勿買 9.0mm（球心
    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
2026-08-03 採購清單：購物車補齊電路料，二極體改 MBRF2045CT
    新增加入購物車（祥昌電子）：4700uF/25V ×4 $120、洞洞板雙面
    7x9cm ×1 $30、多芯線 24AWG 5M 紅/黑各1 $90 —— 祥昌小計 $288
    已過店取 $199 免運。另 buy360-ic MBRF2045CT ×6 $90。
    鋼珠改 2 包 $200。購物車合計約 $908。
    二極體選型變更：原訂 SS54（5A/40V）撐不住 11A 峰值，改用
    MBRF2045CT（45V/20A TO-220）——內含兩顆共陰極二極體，兩腳
    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
2026-08-03 採購清單：4 筆訂單已成立，總付款 $953
    2026-08-03 下單，皆為「待出貨」：
    鼎興科技五金 鋼珠 9.52mm(3/8") 50只 ×2 $200 免運 8/5–8/8
    Mr. ADAPUTA 漆包線 #25/0.5mm 100g ×2 $330 免運 8/5–8/9
    祥昌電子 IR 發射×8/接收×8、4700uF×4、
    洞洞板雙面7×9、多芯線紅黑 $288 免運 8/6–8/10
    buy360-ic MBRF2045CT 45V/20A ×6 $135 含運 8/5–8/8
    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
2026-08-03 移除採購清單中的取貨門市名（公開 repo 不應含位置資訊）
    本 repo 公開於 GitHub。商品連結、規格、價格、賣場名對讀者有用
    且符合開源精神，可以保留；但收件門市屬於位置資訊，移除。
    同一條規範已交代給新建的「採購」session 寫進其 CLAUDE.md：
    收件人姓名、電話、地址、訂單編號、門市資訊一律不得寫入 repo。
    這次是我自己先違反了剛立的規矩，一併修正。
2026-08-03 採購清單：Phase 1 電路料候選調查完成（只調查未下單）
    MOSFET 篩選條件修正：原訂 Rds(on)@4.5V <15mΩ 作廢。實際佔空比僅
    1.03%，11A/TO-220 無散熱片下 16mΩ→溫升1.2°C、50mΩ→3.9°C，
    Rds(on) 不是限制因素。改以 Vgs(th) max ≤2.5V 為硬條件——Vgs 不足
    半導通時 Rds(on) 會跳到歐姆級，那才是燒毀主因。
    四候選比較後首選 IRLZ44N（傑森創工 $25×6=$150，8/5-8/7 到）：
    Vgs(th) max 2.0V 比原訂 IRLB8721 的 2.35V 更適合 3.3V 驅動，
    賣場 9年/4.2萬評價、本品已售 1000+，可信度壓倒性。
    排除兩顆：
    IRL3803 datasheet Vgs(th) 只標 min 1.0V、Max 欄空白，無法驗證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
2026-08-03 採購清單：MOSFET 與線材定案，補上賣場分配兩案比較
    定案：MOSFET 採 IRLZ44N ×6（$150）；18AWG 紅黑各 2m，
    依驅動板到線圈 8.3cm ＋ 繞行彎曲餘裕 20cm/條推算。
    查證 MT899 品項齊備度後確認：兩家都無法單獨買齊——
    MT899 缺矽膠線（只有一般 PVC 多芯線），祥昌缺 T5A 保險絲
    （其 5x20 慢熔只有 30A 單一規格）。
    方案 A（MT899 全包，線材降為一般多芯線）小計 $181，
    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
2026-08-03 採購清單：補強線材判斷理由，方案排序 C > A > B
    線材比較表補上關鍵的一條：矽膠線的優勢集中在會動的部位
    （機器人關節、移動軸、來回擺動的線束），而 v2 是固定裝置，
    線接好就不動，只有組裝與維修拆裝、數十次等級而非數萬次，
    耐反覆彎折這個唯一優勢在本應用用不到。
    加上耐溫與載流量都有餘裕，一般 PVC 多芯線在本應用沒有實質
    劣勢。PVC 唯一小缺點是較硬、剝皮與服貼性差，屬手工焊接舒適度
    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
2026-08-03 採購清單：方案 C 定案，全部集中祥昌一單免運
    David 2026-08-03 確認願意就近購買 T5A 慢熔保險絲，因此採方案 C：
    線材維持原規格的 18AWG 矽膠線，不必為了一顆 $10 的通用耗材
    多開一單付 $45 運費。
    三筆線上訂單：
    祥昌電子 排針、矽膠線紅黑各2m、DC母座、保險絲座、船型開關、
    熱縮套管3m、銅柱M3x4、M3螺絲、絕緣膠帶、紮線帶
    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
2026-08-03 採購清單：必買表第2項同步為 IRLZ44N，補上 IRFZ44N 選購陷阱
    必買表是整份文件最上面的摘要表，只看那張表的人會拿到過時資訊。
    原本規格欄仍寫 IRLB8721PBF、來源欄仍是「蝦皮/露天搜 IRLB8721；
    缺貨替代可用 IRLB3034」，與已定案的 IRLZ44N 不一致。
    更新該列：規格改 IRLZ44N（TO-220、55V/47A、Vgs(th) max 2.0V、
    3.3V 可直驅），來源改傑森創工連結與 $25 單價，並註明原訂
    IRLB8721PBF 亦合格、比較見調查節。
    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
2026-08-03 採購清單：補上運費欄與實付總額 $603，記錄不湊單的理由
    定案表改為商品／運費／小計三欄：
    祥昌電子 $204 ＋ 免運 = $204
    傑森創工 $150 ＋ 運費 $45 = $195
    台達電源 $159 ＋ 運費 $45 = $204
    線上實付約 $603（商品 $513 ＋ 運費 $90），另加 David 自購的
    T5A 保險絲與 M3 螺絲、束線帶。
    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
